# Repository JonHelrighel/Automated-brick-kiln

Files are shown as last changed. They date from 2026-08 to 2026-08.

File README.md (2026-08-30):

# Sistema Automatizado de Cozimento de Tijolos 🧱🔥

Repositório com o desenvolvimento completo do projeto de extensão do curso de **Engenharia de Controle e Automação**, cujo objetivo é projetar e construir um **forno elétrico automatizado** para a queima de tijolos cerâmicos, atendendo à demanda real da **Olaria Modesto** (Rio Grande do Sul).

O projeto é dividido em Atividades de Extensão (AE) semestrais — cada uma corresponde a uma fase do desenvolvimento do produto, seguindo a metodologia do livro *Projeto Integrado de Produtos* (BACK et al.): projeto informacional → conceitual → preliminar → detalhado → automação → retrofit.

> Este repositório é uma organização/documentação pessoal do meu projeto --> **[@JonHelrighel](https://github.com/JonHelrighel)**. O projeto é resultado de trabalho em grupo (autores abaixo) e também existe uma versão mantida por um dos colegas em [EduardoPaz01/AE-Tijolos](https://github.com/EduardoPaz01/AE-Tijolos).

## 👥 Equipe

- Eduardo Paz Putti
- João Emiliano Helrighel Freitas
- Gabriel Dettenborn
- Raian Lobato

**Curso:** Engenharia de Controle e Automação — Chapecó, SC, Brasil

## 🎯 Objetivo geral

Desenvolver e implementar um forno elétrico automatizado, capaz de atingir **até 1100 °C**, com:
- Controle automático de temperatura (malha fechada PI/PID);
- Carregamento e descarregamento automático dos tijolos (carrinho motorizado + porta guilhotina);
- Instrumentação com termopar tipo K e condicionamento de sinal;
- Supervisório (SCADA) com banco de dados e IHM para monitoramento remoto.

## 🗺️ Linha do tempo do projeto (visão geral por AE)

| Etapa | Semestre | Foco | Principais entregas |
|---|---|---|---|
| **[AE-I](./AE-I)** | 5º sem. – 2025/1 | Projeto de Produto (informacional, conceitual, preliminar) | Carta de demanda, fundamentação teórica, dimensionamentos iniciais, modelagem 3D preliminar (CAD) |
| **[AE-II](./AE-II)** | 6º sem. – 2025/2 | Mecânica e Elétrica (construção física) | Projeto mecânico detalhado, fabricação/montagem real do forno, painel elétrico, primeiros ensaios térmicos (dez/2025) |
| **[AE-III](./AE-III)** | 2026/1 | Instrumentação e Controle | Condicionamento de sinal do termopar, identificação do sistema, controladores PI/PID, firmware ESP32, ensaios de malha fechada |
| **[AE-IV](./AE-IV)** | 2026/2 (em andamento) | Automação e Redes / Supervisório | Banco de dados (MySQL), telas de IHM web (HTML), máquina de estados do supervisório |
| **AE-V** | Próximo semestre | Retrofit | Ainda não iniciado |

Cada pasta `AE-*` tem seu próprio `README.md` detalhando o que foi feito naquela etapa e explicando os arquivos/subpastas.

## 🧱 Contexto do problema

A Olaria Modesto fabrica tijolos maciços e furados em fornos a carvão com controle térmico manual e limitado, o que gera perda de peças por queima irregular, baixa agilidade no carregamento/descarregamento e alto consumo de combustível. A proposta do grupo é substituir esse processo por um **forno elétrico automatizado**, com controle preciso de temperatura e movimentação automática das peças — reduzindo perdas e padronizando a qualidade da queima.

## 🛠️ Stack / ferramentas utilizadas ao longo do projeto

- **CAD / Modelagem 3D:** SolidWorks (`.SLDPRT`, `.SLDASM`, `.SLDDRW`), exportações em `.STL` para impressão 3D
- **Simulação de circuitos:** PSIM (`.psimsch`)
- **Simulação de sistemas de controle:** MATLAB/Simulink (`.m`, `.mat`, `.slx`)
- **Diagramas (P&ID, função global, máquina de estados):** draw.io (`.drawio`)
- **Firmware:** ESP32 com ESP-IDF (C) e Arduino (`.ino`)
- **Elétrica:** EPLAN Electric P8 (`.eprj`)
- **Banco de dados:** MySQL Workbench (`.mwb`)
- **Supervisório / IHM:** HTML/JS
- **Documentação:** relatórios em `.docx`, planilhas de projeto em `.xlsx`, apresentações em `.pptx`

## 📁 Estrutura do repositório

```
.
├── AE-I/     → Projeto de produto (informacional, conceitual, preliminar)
├── AE-II/    → Projeto mecânico/elétrico detalhado + construção física
├── AE-III/   → Instrumentação, controle e firmware
├── AE-IV/    → Supervisório, banco de dados e automação de redes
├── AE-V/     → Retrofit (ainda não iniciado)
└── Referências/ → Material de apoio de disciplinas anteriores
```

## ⚠️ Nota sobre arquivos grandes

Este repositório contém arquivos de CAD (`.SLDPRT`, `.SLDASM`, `.STL`), imagens e relatórios que juntos somam algumas centenas de MB. Nenhum arquivo individual ultrapassa o limite de 100 MB do GitHub, mas para repositórios que crescerão mais (novos ensaios, mais fotos, etc.) utilizou-se **Git LFS** para os arquivos de CAD/binários.

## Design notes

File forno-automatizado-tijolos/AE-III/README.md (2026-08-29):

# AE-III — Instrumentação e Controle (2026/1)

## O que foi feito nesta etapa

Com o forno já construído fisicamente (AE-II), a AE-III foca em **instrumentar e controlar** a planta térmica: medir a temperatura de forma confiável, identificar o modelo dinâmico do forno e projetar/testar controladores automáticos (PI e PID) embarcados em um **ESP32**.

Principais atividades:

1. **Revisão do projeto informacional/conceitual** com foco em dinâmica de sistemas e controle.
2. **Instrumentação de temperatura**: termopar tipo K + placa de condicionamento de sinal (amplificação, filtro analógico passa-baixa) e conversão para leitura no ADC do ESP32.
3. **Identificação do sistema (Ensaios do forno)**: ensaios em malha aberta com diferentes níveis de potência (25%, 50%, 75%, 100%) para levantar a função de transferência do forno via MATLAB System Identification.
4. **Projeto de controladores PI e PID**, testados em malha fechada para diferentes referências de temperatura (150 °C, 300 °C, 600 °C) e perfis de rampa, com e sem filtro no sinal medido.
5. **Firmware do ESP32** (ESP-IDF, em C) implementando leitura do ADC, lógica de controle e acionamento das portas/motor.
6. **Peças mecânicas adicionais**: base/caixa e tampa do processador (impressas em 3D), sistema de fim de curso (chave/obstáculo) para detectar a posição da porta/carrinho.
7. **Projeto elétrico** completo no EPLAN (conjuntos "Controladora" e "Periféricos").
8. Relatório e apresentação da etapa, com sugestões de melhoria (filtro digital dedicado, isolação térmica melhor, alimentação trifásica para atingir a taxa de subida de 15 °C/min exigida).

## Estrutura da pasta

| Pasta/arquivo | Conteúdo |
|---|---|
| `AE3 Tijolos - Relatório.docx` / `AE3_Tijolos_VERSAO FINAL_.docx` | Relatório da etapa (versão de trabalho e versão final): introdução, objetivo geral, revisão de projeto, fundamentação teórica sobre sensores de temperatura, resultados dos ensaios de controle e sugestões de melhoria |
| `AE3 - Tijolos Apr. Inicial_.pptx` | Apresentação inicial do semestre |
| `código fim de curso.txt` | Anotações/código relacionado ao sistema de fim de curso (detecção de posição) |
| `divisor resistivo PI FORNO.psimsch` | Simulação PSIM do divisor resistivo usado no condicionamento do sinal do termopar |
| `Draw.IO (ESQUEMAS)/` | Diagramas: função global e desdobramentos da AE-III, e o **P&ID** completo do sistema (`P&ID AEIII` + PNG exportado) |
| `Projeto Elétrico/` | Projeto elétrico em EPLAN (`AE.eprj`), biblioteca de símbolos do ESP32 (`.elibz`) e PDFs dos conjuntos "Controladora" e "Periféricos" |
| `Projetos (PLANILHAS DOCS)/` | Checklist, projeto conceitual/informacional atualizados (`.xlsx`) e cronograma de prazos |
| `Impressões 3D (Arquivos STL)/` | Peça `ApoioIHM` (suporte da IHM), modelo nativo e STL para impressão |
| `Mecânica/` | Peças mecânicas da etapa: caixa/tampa/base do processador (com STL para impressão 3D e revisões), pontes H, e subpasta `Sistema do FimCurso/` (peça obstáculo + switch, usadas para detectar fim de curso da porta/carrinho) |
| `Programa de IOS ESP32/` | **Firmware do ESP32** — veja detalhamento abaixo |
| `ENSAIOS FORNO (25,50,75,100)/` | **Identificação do sistema**: ensaios em malha aberta a 25%, 50%, 75% e 100% de potência, com scripts MATLAB (`.m`), modelos identificados (`.mat`, `.slx`), gráficos e uma subpasta com o projeto de controlador PI/PID já filtrado |
| `ENSAIOS CONTROLE (TXT)/` | Dados brutos (`.txt`) dos ensaios em malha fechada: controle PI/PID para referências de 150 °C, 300 °C, 600 °C, com e sem filtro, além de rampa 50→150 °C e testes de termopar |
| `SUBIR PRO DRIVE ESSA PASTA/` | Projeto MATLAB do filtro digital do sinal do termopar (`Código Filtro Forno.m`) e workspace salvo (`.mat`), preparados para compartilhamento no Drive do grupo |

### `Programa de IOS ESP32/` — detalhamento do firmware

| Pasta | O que é |
|---|---|
| `main/` | **Código-fonte principal e mais atual** do firmware ESP-IDF: `main.c` + módulos `adc.c/h` (leitura do termopar), `controle.c/h` (lógica PI/PID), `controle_portas.c/h` (acionamento da porta/motor) e `temporizador.c/h` |
| `PROGRAMA ESP32AEIII/` | Cópia/versão paralela do mesmo firmware (mesma estrutura de `main/src`) |
| `testeESP/`, `Nova pasta/teste_forno/` | Projetos de teste do ESP-IDF — **as pastas `build/` geradas por esses projetos foram removidas** desta organização (artefatos de compilação, não código-fonte) |
| `sketch_mar27a/`, `ProgramaEsp_copy_20260320090435/` | Sketches Arduino (`.ino`) de testes pontuais/simulações |
| `Maquina de Estados Forno.drawio` | Diagrama da máquina de estados do firmware do forno |
| `DadosSimuladosEsp32.m` / `.txt`, `GraficoSimulado.jpg` | Dados e gráfico de uma simulação do comportamento do ESP32 |
| `Padronização de nomes.txt` | Convenção de nomes usada no código/projeto |
| `Untitled_0.CoolTermSettings`, `CurrentSession.CoolTermSession` | Configurações do terminal serial CoolTerm usado para monitorar a UART do ESP32 |

> ℹ️ **Nota:** os arquivos gerados por build do ESP-IDF (`build/`, `CMakeFiles/`, `esp-idf/`, bibliotecas `.a`, etc.) foram excluídos ao organizar este repositório — juntos ocupavam ~280 MB e podem ser 100% recriados a partir do código-fonte com `idf.py build`. Eles já estão listados no `.gitignore` da raiz.

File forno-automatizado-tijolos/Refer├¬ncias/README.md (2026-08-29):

# Referências

Material de apoio de disciplinas anteriores do curso, usado como base/referência para a redação dos relatórios das Atividades de Extensão (ex.: trabalho da disciplina de Introdução à Engenharia de Controle e Automação). Não faz parte do desenvolvimento técnico do forno em si.

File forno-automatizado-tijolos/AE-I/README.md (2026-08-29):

# AE-I — Projeto de Produto (5º semestre – 2025/1)

## O que foi feito nesta etapa

A AE-I é a fase inicial do projeto, focada na **concepção e documentação técnica** do forno automatizado, antes de qualquer construção física. Seguindo a metodologia de *Projeto Integrado de Produtos* (BACK et al.), o grupo percorreu:

1. **Carta de demanda** — levantamento da necessidade real da Olaria Modesto (RS): dificuldade no carregamento/descarregamento manual de tijolos e ausência de controle preciso de temperatura em fornos a carvão.
2. **Projeto informacional** — fundamentação teórica (histórico do tijolo, processo de fabricação cerâmica, estudo de caso da Cerâmica Pallotti) e definição dos requisitos do produto.
3. **Projeto conceitual** — geração e seleção de concepções para a solução (estrutura do forno, sistema de movimentação, IHM, painel elétrico).
4. **Projeto preliminar (1 e 2)** — primeiras modelagens 3D e dimensionamentos (corrente, motor, tijolos) para validar as concepções escolhidas.
5. Apresentações intermediária e final do semestre.

## Estrutura da pasta

| Pasta/arquivo | Conteúdo |
|---|---|
| `AE1 Tijolos - Carta de demanda/` | PDF com a carta de demanda de soluções tecnológicas da Olaria Modesto |
| `AE1 Tijolos - MPP.docx` | Relatório principal (Metodologia de Projeto de Produto): introdução, demanda, fundamentação teórica, projeto informacional/conceitual e referências |
| `AE1 Tijolos - Rascunho Manual.docx` | Rascunho/anotações manuscritas digitalizadas do desenvolvimento do relatório |
| `AE1 Tijolos - Projeto Informacional.xlsx` | Planilha com requisitos e especificações do produto |
| `AE1 Tijolos - Projeto Concentual.xlsx` | Planilha de geração/avaliação de concepções (matriz de decisão) |
| `AE1 Tijolos - Funcao Global e Desdobramentos.drawio` | Diagrama da função global do sistema e seus desdobramentos (entradas/saídas/subsistemas) |
| `AE1 Tijolos - Dimensionamentos/` | Cálculos de dimensionamento em SMath (`.sm`): corrente de transmissão, motor e tijolos |
| `AE1 Tijolos- Projeto Preliminar 1/` | Primeira rodada de modelagem 3D preliminar, organizada por subsistema: `CARRINHO`, `FORNO`, `IHM`, `MESA DE APOIO PRO FORNO`, `MOTOR`, `MOVIMENTAÇÃO DO CARRINHO`, `OUTRAS...` (catálogos de peças comerciais), `PAINEL ELÉTRICO`, `PORTA FORNO`, `TRILHO` |
| `AE1 Tijolos - Projeto Preliminar 2/` | Segunda rodada de projeto preliminar, refinando a modelagem anterior |
| `Montagens/` | Conjuntos montados em SolidWorks (`.SLDASM`) com desenhos técnicos (`.SLDDRW`) e PDFs exportados (ex.: `CT-00-00-XX`, `ESP_00_00_XX`) |
| `Peças/` | Peças individuais modeladas em SolidWorks (`.SLDPRT`), com desenho técnico e PDF de cada peça (nomenclatura por conjunto: `CSS`, `CT`, `ENG`, `ESP`, `ETI`, `MC`, `SPM`) |
| `AE1 Tijolos - Apr. Inicial (30-04).pptx` | Apresentação de meio de semestre |
| `AE1 Tijolos - Apr.  Festa Junina.pptx` | Apresentação em evento intermediário (Festa Junina) |
| `AE1 Tijolos - Apr. Final (16-07).pptx` | Apresentação final da AE-I |

## Convenção de nomenclatura das peças

As peças/conjuntos seguem códigos por subsistema, por exemplo:
- `CT` — Carrinho
- `ESP` — Espelho / estrutura
- `CSS`, `ENG`, `ETI`, `MC`, `SPM` — demais componentes e subconjuntos mecânicos

Cada código de peça possui até 3 arquivos irmãos: `.SLDPRT`/`.SLDASM` (modelo nativo do SolidWorks), `.SLDDRW` (desenho técnico) e `.PDF` (exportação para consulta sem precisar do SolidWorks instalado).

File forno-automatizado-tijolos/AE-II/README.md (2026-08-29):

# AE-II — Mecânica e Elétrica (6º semestre – 2025/2)

## O que foi feito nesta etapa

A AE-II é a fase de **construção física** do protótipo: o grupo saiu da modelagem 3D e partiu para a fabricação e montagem real do forno, do carrinho, da porta e do painel elétrico, além de revisar o projeto mecânico com base nas dificuldades encontradas na oficina.

Principais atividades:

1. **Revisão do projeto mecânico** (pasta `REVISAO`), incorporando ajustes descobertos durante a fabricação (ex.: adição de um novo subsistema `TAMBOR`, não previsto na AE-I).
2. **Dimensionamento das resistências elétricas** e do circuito de acionamento (simulação em PSIM).
3. **Fabricação e montagem física**, documentada dia a dia em fotos (pasta `AE2 - imagens relatório`, com uma subpasta por data de setembro a dezembro de 2025): corte e soldagem das chapas, montagem da caixa do forno, instalação da porta e isolamento térmico, montagem do painel elétrico, etc.
4. **Primeiros ensaios térmicos do protótipo montado**, em dezembro de 2025. No primeiro acionamento (17/12/2025) a temperatura atingida foi de aproximadamente 170 °C, evidenciando vazamentos térmicos que motivaram melhorias no isolamento.
5. **Descrição do P&ID** (diagrama de tubulação e instrumentação) do sistema.
6. Checklist de entregas e relatório final da etapa.

## Estrutura da pasta

| Pasta/arquivo | Conteúdo |
|---|---|
| `AE2 Tijolos - Relatório final.docx` | Relatório completo da etapa: introdução, demanda, justificativa, fundamentação teórica (termopar tipo K, transmissor HT-010, ponte H, etc.), resultados dos primeiros ensaios térmicos e conclusão |
| `AE2 - Tijlos Checklist.xlsx` | Checklist de itens/entregas da atividade |
| `AE2 - Tijolos Apr. Inicial (14-08).pptx` | Apresentação inicial do semestre |
| `P&ID descrição.xlsx` | Descrição textual do diagrama P&ID do sistema (instrumentos, malhas de controle, tubulação/fiação) |
| `AE2 - Tijolos Dimensionamentos/` | `AE2 - Esquema elétrico.psimsch` (simulação PSIM do circuito de acionamento das resistências) e `dimensionamento resistencias.sm` (cálculo de potência/dimensionamento das resistências de aquecimento) |
| `AE2 - Tijolos Projeto mecânico/` | Modelagem mecânica "como projetado" antes das correções de fabricação, organizada por subsistema: `CARRINHO`, `FORNO`, `IHM`, `MESA DE APOIO PRO FORNO`, `MOTOR`, `MOVIMENTAÇÃO DO CARRINHO`, `PAINEL ELÉTRICO`, `PORTA FORNO`, `TRILHO` |
| `REVISAO - AE2 - Tijolos Projeto mecânico/` | Versão **revisada** do projeto mecânico após ajustes de fabricação — mesmos subsistemas da pasta anterior, mais o novo subsistema `TAMBOR` |
| `AE2 - imagens relatório/` | **Diário fotográfico da montagem**, com uma pasta por data (de `set - 25 de setembro` até `dez - 18 de dezembro`), registrando cada etapa da fabricação: corte/solda das chapas, montagem da caixa e da porta, isolamento térmico, fabricação de eixos, montagem do painel elétrico e testes iniciais do forno já carregado |

## Linha do tempo da construção (pelas fotos)

- **Set/2025:** corte de chapas, soldagem da caixa do forno, isolamento das portas
- **Out/2025:** furação dos trilhos, montagem dos suportes da porta, fabricação de eixos, montagem da caixa do painel elétrico
- **Nov/2025:** porta soldada com dobradiça, corte de tijolos para teste, recepção dos tijolos de teste
- **Dez/2025:** apresentação do forno montado, forno carregado no carrinho, painel com fonte e contactora, ajustes finais e reposicionamento de suportes — **primeiros ensaios térmicos**

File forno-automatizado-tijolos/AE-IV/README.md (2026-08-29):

# AE-IV — Automação e Redes / Supervisório (2026/2 — em andamento)

## O que foi feito nesta etapa

Com o controle de temperatura já validado na AE-III, a AE-IV foca em **automação de redes e supervisório**: dar visibilidade remota ao processo por meio de um sistema SCADA simplificado, com banco de dados para histórico e uma IHM web para operação/monitoramento.

Principais atividades (em andamento):

1. **Modelagem do banco de dados** do forno (MySQL Workbench), armazenando dados de processo (temperatura, estado do ciclo, eventos).
2. **Máquina de estados do supervisório**, definindo os modos de operação do sistema (parado, aquecendo, patamar, resfriando, alarme, etc.).
3. **Desenvolvimento das telas da IHM** em HTML/JS, para visualização e controle do forno via navegador.
4. Planejamento de atividades e rubrica de avaliação da etapa.

## Estrutura da pasta

| Pasta/arquivo | Conteúdo |
|---|---|
| `Atividades de Extensão V_1 2026.docx` | Rascunho do relatório da etapa (estrutura de conclusão, sugestões de melhoria e documentos complementares) |
| ` AE4 - Tijolos Apr. Inicial_.pptx` | Apresentação inicial do semestre |
| `2026-2 - AE4 - Rubrica para Avaliação AE.xlsx` | Rubrica de avaliação da atividade, fornecida pela coordenação do curso |
| `Maquina de estados Supervisório.drawio` (+ `.png`) | Diagrama da máquina de estados do sistema supervisório |
| `Banco de Dados/` | Modelo do banco de dados do forno em MySQL Workbench: `banco_forno.mwb` (modelo atual) e `.mwb.bak` (backup) |
| `Programas-Codigos/Codigos Telas/` | Telas HTML da IHM web (ex.: `1_parametros.html`, `Tela_IHM.html`) para visualização/ajuste de parâmetros do processo |
| `supervisorio_sql_tarefas_Validar com o grupo.xlsx` | Planilha de tarefas do supervisório/SQL, para validação com o grupo |
| `Planejamento de Atividades/` | Planejamento do semestre e cópia da rubrica de avaliação |

## Status

Etapa em andamento no semestre 2026/2 — a documentação final e o relatório completo ainda serão produzidos ao longo do semestre.

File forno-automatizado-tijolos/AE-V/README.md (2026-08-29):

# AE-V — Retrofit (próximo semestre)

Esta etapa ainda **não foi iniciada**. Segundo os relatórios das etapas anteriores, a AE-V terá como foco o **retrofit** do sistema — ou seja, revisar e modernizar partes do projeto (mecânica, elétrica, controle e/ou supervisório) com base no aprendizado acumulado nas etapas AE-I a AE-IV.

Esta pasta foi criada como placeholder para manter a estrutura do repositório consistente com as demais etapas. Assim que o trabalho for iniciado, este README deve ser atualizado com:

- Objetivo específico do retrofit;
- O que foi revisado/alterado em relação às etapas anteriores;
- Resultados e conclusões.

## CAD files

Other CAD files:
forno-automatizado-tijolos/AE-I/AE1 Tijolos - Projeto Preliminar 2/Projeto Preliminar/CARRINHO/Montagens/CAR_00_00_00.SLDASM
forno-automatizado-tijolos/AE-I/AE1 Tijolos - Projeto Preliminar 2/Projeto Preliminar/FORNO/Montagens/FNR-00-03-01.SLDASM
forno-automatizado-tijolos/AE-I/AE1 Tijolos - Projeto Preliminar 2/Projeto Preliminar/MESA DE APOIO PRO FORNO/Montagem/MSA-00-00-00.SLDASM
forno-automatizado-tijolos/AE-I/AE1 Tijolos - Projeto Preliminar 2/Projeto Preliminar/MOVIMENTA├ç├âO DO CARRINHO/Montagens/ESP_00_00_02.SLDASM
forno-automatizado-tijolos/AE-I/AE1 Tijolos - Projeto Preliminar 2/Projeto Preliminar/PORTA FORNO/montagem/POR_00_03_00.SLDASM
forno-automatizado-tijolos/AE-I/AE1 Tijolos - Projeto Preliminar 2/Projeto Preliminar/TRILHO/Montagem/TRI_00_00_00.SLDASM
forno-automatizado-tijolos/AE-I/AE1 Tijolos- Projeto Preliminar 1/CARRINHO/Montagens/CAR_00_01_00.SLDASM
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

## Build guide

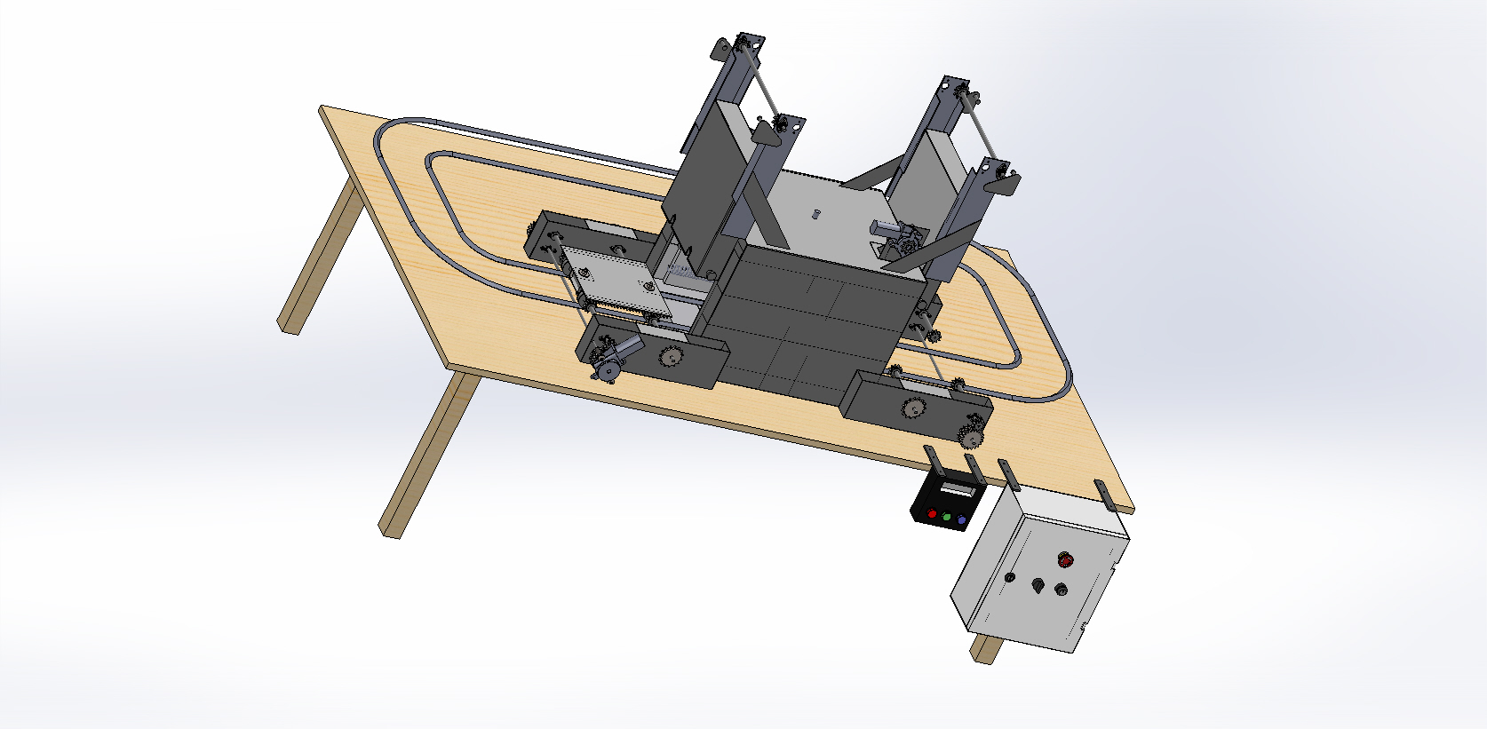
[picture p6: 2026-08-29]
forno-automatizado-tijolos/AE-I/AE1 Tijolos - Projeto Preliminar 2/Projeto Preliminar/FORNO/Montagens/FNR-00-04-01.JPG

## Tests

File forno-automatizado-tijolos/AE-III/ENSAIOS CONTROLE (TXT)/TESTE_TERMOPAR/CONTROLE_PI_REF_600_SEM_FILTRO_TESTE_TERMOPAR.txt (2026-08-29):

ets Jul 29 2019 12:21:46

rst:0x1 (POWERON_RESET),boot:0x12 (SPI_FAST_FLASH_BOOT)
configsip: 0, SPIWP:0xee
clk_drv:0x00,q_drv:0x00,d_drv:0x00,cs0_drv:0x00,hd_drv:0x00,wp_drv:0x00
mode:DIO, clock div:2
load:0x3fff0040,len:6272
load:0x40078000,len:15848
load:0x40080400,len:3920
entry 0x40080644
I (27) boot: ESP-IDF v6.0 2nd stage bootloader
I (27) boot: compile time Apr 23 2026 08:09:33
I (28) boot: Multicore bootloader
I (29) boot: chip revision: v3.1
I (31) boot.esp32: SPI Speed      : 40MHz
I (35) boot.esp32: SPI Mode       : DIO
I (39) boot.esp32: SPI Flash Size : 2MB
I (42) boot: Enabling RNG early entropy source...
I (47) boot: Partition Table:
I (49) boot: ## Label            Usage          Type ST Offset   Length
I (56) boot:  0 nvs              WiFi data        01 02 00009000 00006000
I (62) boot:  1 phy_init         RF data          01 01 0000f000 00001000
I (69) boot:  2 factory          factory app      00 00 00010000 00100000
I (75) boot: End of partition table
I (79) esp_image: segment 0: paddr=00010020 vaddr=3f400020 size=09658h ( 38488) map
I (100) esp_image: segment 1: paddr=00019680 vaddr=3ffb0000 size=02a2ch ( 10796) load
I (104) esp_image: segment 2: paddr=0001c0b4 vaddr=40080000 size=03f64h ( 16228) load
I (111) esp_image: segment 3: paddr=00020020 vaddr=400d0020 size=0f5d4h ( 62932) map
I (134) esp_image: segment 4: paddr=0002f5fc vaddr=40083f64 size=06e18h ( 28184) load
I (145) esp_image: segment 5: paddr=0003641c vaddr=50000000 size=00028h (    40) load
I (151) boot: Loaded app from partition at offset 0x10000
I (152) boot: Disabling RNG early entropy source...
I (164) cpu_start: Multicore app
I (172) cpu_start: GPIO 3 and 1 are used as console UART I/O pins
I (172) cpu_start: Pro cpu start user code
I (172) cpu_start: cpu freq: 160000000 Hz
I (174) app_init: Application information:
I (178) app_init: Project name:     app-template
I (182) app_init: App version:      1
I (186) app_init: Compile time:     Apr 23 2026 08:07:59
I (191) app_init: ELF file SHA256:  187407ae9...
I (195) app_init: ESP-IDF:          v6.0
I (199) efuse_init: Min chip rev:     v0.0
I (202) efuse_init: Max chip rev:     v3.99 
I (206) efuse_init: Chip rev:         v3.1
I (211) heap_init: Initializing. RAM available for dynamic allocation:
I (217) heap_init: At 3FFAE6E0 len 00001920 (6 KiB): DRAM
I (222) heap_init: At 3FFB3410 len 0002CBF0 (178 KiB): DRAM
I (227) heap_init: At 3FFE0440 len 00003AE0 (14 KiB): D/IRAM
I (232) heap_init: At 3FFE4350 len 0001BCB0 (111 KiB): D/IRAM
I (238) heap_init: At 4008AD7C len 00015284 (84 KiB): IRAM
I (245) spi_flash: detected chip: generic
I (247) spi_flash: flash io: dio
W (250) spi_flash: Detected size(4096k) larger than the size in the binary image header(2048k). Using the size in the binary image header.
I (263) main_task: Started on CPU0
I (273) main_task: Calling app_main()
1,1604,41.64,0.000000 
2,1604,41.64,9.235869 
3,1601,40.04,9.237197 
4,1602,40.57,9.265125 
5,1600,39.50,9.257590 
6,1595,36.82,9.276654 
7,1600,39.50,9.322321 
8,1588,33.07,9.279327 
9,1598,38.43,9.387060 
10,1600,39.50,9.299742 
11,1596,37.36,9.283344 
Forno LIGADOForno LIGADOForno LIGADOForno LIGADOForno LIGADOForno LIGADOForno LIGADOForno LIGADOForno LIGADOForno LIGADOForno LIGADOForno LIGADOForno LIGADOForno LIGADO12,1600,39.50,9.320144 
13,1600,39.50,9.286016 
14,1600,39.50,9.287349 
15,1594,36.28,9.288682 
16,1579,28.24,9.343215 
17,1603,41.11,9.477556 
18,1598,38.43,9.266115 
19,1591,34.68,9.311778 
20,1559,17.52,9.375181 
21,1602,40.57,9.660259 
22,1607,43.25,9.280377 
23,1604,41.64,9.237374 
24,1605,42.18,9.265299 
25,1602,40.57,9.257760 
26,1648,65.23,9.285686 
27,1606,42.72,8.879150 
28,1601,40.04,9.252823 
29,1612,45.93,9.298481 
30,1613,46.47,9.202280 
31,1610,44.86,9.194731 
32,1614,47.00,9.222648 
33,1611,45.40,9.188501 
34,1616,48.08,9.216416 
35,1610,44.86,9.173402 
36,1613,46.47,9.227915 
37,1617,48.61,9.202636 
38,1603,41.11,9.168485 
39,1615,47.54,9.293930 
40,1616,48.08,9.188859 
41,1621,50.76,9.181307 
42,1616,48.08,9.138286 
43,1623,51.83,9.183926 
44,1621,50.76,9.123172 
45,1626,53.44,9.142209 
46,1622,51.29,9.099182 
47,1623,51.83,9.135948 
48,1622,51.29,9.128386 
49,1630,55.58,9.138557 
50,1629,55.05,9.068929 
51,1629,55.05,9.079090 
52,1637,59.33,9.080387 
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

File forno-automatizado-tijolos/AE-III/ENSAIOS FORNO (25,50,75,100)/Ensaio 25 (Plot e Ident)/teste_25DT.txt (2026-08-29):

19,0,0.00
20,0,0.00
21,45,15.35
22,11,3.75
23,11,3.75
24,0,0.00
25,30,10.23
26,43,14.67
27,16,5.46
28,42,14.33
29,43,14.67
30,56,19.10
31,26,8.87
32,38,12.96
33,11,3.75
34,44,15.01
35,37,12.62
36,21,7.16
37,55,18.76
38,11,3.75
39,39,13.30
40,16,5.46
41,21,7.16
42,77,26.27
43,68,23.20
44,53,18.08
45,44,15.01
46,16,5.46
47,48,16.37
48,39,13.30
49,40,13.65
50,25,8.53
51,59,20.13
52,47,16.03
53,60,20.47
54,3,1.02
55,48,16.37
56,39,13.30
57,64,21.83
58,17,5.80
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

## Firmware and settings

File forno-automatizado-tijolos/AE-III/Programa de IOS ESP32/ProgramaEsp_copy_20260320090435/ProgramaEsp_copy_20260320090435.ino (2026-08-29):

// ========================================================
// PROGRAMA EM ESP-IDF (FreeRTOS) – Equivalente nativo ESP32
// (sem framework Arduino – equivalente ao "AVR bare-metal")
// Baseado na imagem do ESP32-DevKitC-K1 + Datasheet oficial
// https://documentation.espressif.com/esp32_datasheet_en.pdf
//
// Funções:
// - Leitura analógica 12 bits (GPIO34/35 – ADC1_CH6/CH7)
// - Atuação na resistência (saída digital)
// - Controle dos motores (saídas digitais)
//
// Pinos 100% compatíveis com a imagem e com o datasheet (Tabela 2 e seção 4):
// GPIO34 = ADC1_CH6 (input-only)
// GPIO35 = ADC1_CH7 (input-only)
// GPIO21, GPIO18, GPIO19, GPIO27, GPIO26 = full digital output + PWM
// ========================================================

#include <stdio.h>
#include "freertos/FreeRTOS.h"
#include "freertos/task.h"
#include "driver/gpio.h"
#include "driver/adc.h"
#include "esp_log.h"
#include "driver/dac.h"
#include "driver/ledc.h"

static const char *TAG = "ESP32_IO";

// === PINOS ===

#define R1_IN1_GPIO          (gpio_num_t)10   // ADC1_CH6  (R1-IN1)
#define R1_IN2_GPIO          (gpio_num_t)11   // ADC1_CH7  (R1-IN2)

#define DAC_2 (gpio_num_t)25
#define DAC_2 (gpio_num_t)26 

#define SPI_CLK (gpio_num_t)14
#define SPI_MISO (gpio_num_t)12
#define SPI_MOSI (gpio_num_t)13

#define SCL (gpio_num_t)22
#define SDA (gpio_num_t)21

#define MOTOR1_SAIDA1_GPIO   (gpio_num_t)19   // MOTOR1-SAIDA1
#define MOTOR1_SAIDA2_GPIO   (gpio_num_t)18   // MOTOR1-SAIDA2
#define RESISTENCIA_SAIDA_GPIO (gpio_num_t)5 // RESISTENCIA-SAIDA3

#define UART_TX (gpio_num_t)41 
#define UART_RX (gpio_num_t)40

#define MOTOR2_SAIDA1_GPIO   (gpio_num_t)2   // MOTOR2-SAIDA1
#define MOTOR2_SAIDA2_GPIO   (gpio_num_t)15   // MOTOR2-SAIDA2

void setup(){
    ESP_LOGI(TAG, "=== ESP32 ESP-IDF + FreeRTOS iniciado (baseado na imagem) ===");

    // ================== CONFIGURAÇÃO DAS SAÍDAS DIGITAIS ==================
    gpio_set_direction(MOTOR1_SAIDA1_GPIO,   GPIO_MODE_OUTPUT);
    gpio_set_direction(MOTOR1_SAIDA2_GPIO,   GPIO_MODE_OUTPUT);
    gpio_set_direction(RESISTENCIA_SAIDA_GPIO, GPIO_MODE_OUTPUT);
    gpio_set_direction(MOTOR2_SAIDA1_GPIO,   GPIO_MODE_OUTPUT);
    gpio_set_direction(MOTOR2_SAIDA2_GPIO,   GPIO_MODE_OUTPUT);
    gpio_set_direction(SPI_CLK,   GPIO_MODE_OUTPUT);
    gpio_set_direction(SPI_MISO,   GPIO_MODE_OUTPUT);
    gpio_set_direction(SPI_MOSI,   GPIO_MODE_OUTPUT);
    gpio_set_direction(UART_TX,   GPIO_MODE_OUTPUT);
    gpio_set_direction(UART_RX,   GPIO_MODE_OUTPUT);

    // Estado inicial seguro (tudo desligado)
    gpio_set_level(MOTOR1_SAIDA1_GPIO,   0);
    gpio_set_level(MOTOR1_SAIDA2_GPIO,   0);
    gpio_set_level(RESISTENCIA_SAIDA_GPIO, 0);
    gpio_set_level(MOTOR2_SAIDA1_GPIO,   0);
    gpio_set_level(MOTOR2_SAIDA2_GPIO,   0);
    gpio_set_level(SPI_CLK, 0);
    gpio_set_level(SPI_MISO, 0);
    gpio_set_level(SPI_MOSI, 0);
    gpio_set_level(UART_TX, 0);
    gpio_set_level(UART_RX, 0);

    // ================== CONFIGURAÇÃO ADC 12 BITS (datasheet seção 4.2) ==================
    adc1_config_width(ADC_WIDTH_BIT_12);                    // Resolução 12 bits (0-4095)
    adc1_config_channel_atten(ADC1_CHANNEL_6, ADC_ATTEN_DB_11); // GPIO34 – faixa ~0-3,3V
    adc1_config_channel_atten(ADC1_CHANNEL_7, ADC_ATTEN_DB_11); // GPIO35 – faixa ~0-3,3V
}


void TesteDigitais(void)
{
    gpio_set_level(MOTOR1_SAIDA1_GPIO, 1);
    gpio_set_level(MOTOR1_SAIDA2_GPIO, 1);
    gpio_set_level(MOTOR2_SAIDA1_GPIO, 1);
    gpio_set_level(MOTOR2_SAIDA2_GPIO, 1);
    gpio_set_level(SPI_CLK, 1);
    gpio_set_level(SPI_MISO, 1);
    gpio_set_level(SPI_MOSI, 1);
    gpio_set_level(UART_TX, 1);
    gpio_set_level(UART_RX, 1);
    gpio_set_level(RESISTENCIA_SAIDA_GPIO, 1);
    vTaskDelay(pdMS_TO_TICKS(100));

    gpio_set_level(MOTOR1_SAIDA1_GPIO, 0);
    gpio_set_level(MOTOR1_SAIDA2_GPIO, 0);
    gpio_set_level(MOTOR2_SAIDA1_GPIO, 0);
    gpio_set_level(MOTOR2_SAIDA2_GPIO, 0);
    gpio_set_level(SPI_CLK, 0);
    gpio_set_level(SPI_MISO, 0);
    gpio_set_level(SPI_MOSI, 0);
    gpio_set_level(UART_TX, 0);
    gpio_set_level(UART_RX, 0);
    gpio_set_level(RESISTENCIA_SAIDA_GPIO, 0);
    vTaskDelay(pdMS_TO_TICKS(100));
}

// =====================TESTE DAC (RAMPA 0 → 255 em exatamente 2 segundos) ======================
void TesteDAC(void)
{
    ESP_LOGI("TESTE_DAC", "Iniciando rampa de tensão DAC (0 → 255 em 2 segundos)...");

    // Habilita os canais DAC (GPIO25 = DAC1 e GPIO26 = DAC2 conforme datasheet e imagem)
    dac_output_enable(DAC_CHANNEL_1);
    dac_output_enable(DAC_CHANNEL_2);

    // Rampa suave: 256 passos em 2000 ms → delay de ~7,8 ms por passo
    for (int valor = 0; valor <= 255; valor++) {
        dac_output_voltage(DAC_CHANNEL_1, valor);   // DAC-1
        dac_output_voltage(DAC_CHANNEL_2, valor);   // DAC-2 (mesma rampa)
    }

    // Volta para 0V no final do teste
    dac_output_voltage(DAC_CHANNEL_1, 0);
    dac_output_voltage(DAC_CHANNEL_2, 0);

    ESP_LOGI("TESTE_DAC", "Rampa DAC concluída (tensão máxima atingida e retornada a 0V)");
}

void TestePWM(void)
{

    ESP_LOGI("TESTE_PWM", "Iniciando teste PWM rampa duty (pino %d)", MOTOR1_SAIDA1_GPIO);

    // Configuração do timer PWM
    ledc_timer_config_t timer_config = {
        .speed_mode       = LEDC_LOW_SPEED_MODE,
        .duty_resolution  = LEDC_TIMER_10_BIT,
        .timer_num        = LEDC_TIMER_0,
        .freq_hz          = 5000,
        .clk_cfg          = LEDC_AUTO_CLK
    };
    ESP_ERROR_CHECK(ledc_timer_config(&timer_config));

    // Canal PWM – ordem correta dos campos (igual ao header ledc.h)
    ledc_channel_config_t channel_config = {
        .gpio_num       = MOTOR1_SAIDA1_GPIO,
        .speed_mode     = LEDC_LOW_SPEED_MODE,
        .channel        = LEDC_CHANNEL_0,
        .intr_type      = LEDC_INTR_DISABLE,
        .timer_sel      = LEDC_TIMER_0,
        .duty           = 0,
        .hpoint         = 0
    };
    ESP_ERROR_CHECK(ledc_channel_config(&channel_config));

    // Rampa de duty 0 → 1023 em ~2 segundos
    const int passos = 1024;
    const int delay_por_passo = 2000 / passos;  // ≈ 1.95 ms por passo

    for (int duty = 0; duty <= 1023; duty++) {
        ledc_set_duty(LEDC_LOW_SPEED_MODE, LEDC_CHANNEL_0, duty);
        ledc_update_duty(LEDC_LOW_SPEED_MODE, LEDC_CHANNEL_0);
        vTaskDelay(pdMS_TO_TICKS(delay_por_passo));
    }

    // Desliga no final
    ledc_set_duty(LEDC_LOW_SPEED_MODE, LEDC_CHANNEL_0, 0);
    ledc_update_duty(LEDC_LOW_SPEED_MODE, LEDC_CHANNEL_0);

    ESP_LOGI("TESTE_PWM", "Rampa PWM finalizada");
}

void TestADC(){
    int read = analogRead(0);
}

void loop(){
    //TestePWM();
    TesteDigitais();
    TesteDAC();
}

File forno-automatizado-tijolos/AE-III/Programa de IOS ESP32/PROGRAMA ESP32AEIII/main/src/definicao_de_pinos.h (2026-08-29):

/*
 * definicao_de_pinos.h
 *
 *  Created on: 13 de abr. de 2026
 *      Author: Gabriel
 */

#ifndef MAIN_SRC_DEFINICAO_DE_PINOS_H_
#define MAIN_SRC_DEFINICAO_DE_PINOS_H_

#include "driver/gpio.h"
#include "hal/gpio_types.h"
#include "soc/gpio_num.h"

#define DEBUG 0

#define PINO_LIGA GPIO_NUM_5
#define PINO_INICIAR GPIO_NUM_22
#define PINO_MOTOR_E GPIO_NUM_19
#define PINO_MOTOR_D GPIO_NUM_18

void setup_pinos(){
	gpio_set_direction(PINO_LIGA, GPIO_MODE_INPUT);
	gpio_set_direction(PINO_INICIAR, GPIO_MODE_INPUT);
	gpio_set_direction(PINO_MOTOR_D, GPIO_MODE_OUTPUT);
	gpio_set_direction(PINO_MOTOR_E, GPIO_MODE_OUTPUT);
}

#endif /* MAIN_SRC_DEFINICAO_DE_PINOS_H_ */

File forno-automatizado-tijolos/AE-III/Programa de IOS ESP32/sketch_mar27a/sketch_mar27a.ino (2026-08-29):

// ========================================================
// PROGRAMA EM ESP-IDF (FreeRTOS) – Equivalente nativo ESP32
// (sem framework Arduino – equivalente ao "AVR bare-metal")
// Baseado na imagem do ESP32-DevKitC-K1 + Datasheet oficial
// https://documentation.espressif.com/esp32_datasheet_en.pdf
//
// Funções:
// - Leitura analógica 12 bits (GPIO34/35 – ADC1_CH6/CH7)
// - Atuação na resistência (saída digital)
// - Controle dos motores (saídas digitais)
// - Teste DAC (GPIO25 = DAC1, GPIO26 = DAC2)
// - Teste PWM via LEDC
//
// CORREÇÕES APLICADAS:
// [1] analogRead() removido — não existe no ESP-IDF; substituído por adc1_get_raw()
// [2] R1_IN1/IN2 corrigidos: GPIO10/11 → GPIO34/35 (ADC1_CH6/CH7, input-only)
// [3] DAC_2 definido duas vezes (GPIO25 e GPIO26) → corrigido para DAC_1/DAC_2
// [4] UART_RX não deve ser configurado como GPIO_MODE_OUTPUT → removido do set_direction
// [5] GPIO34/35 são input-only — NÃO chamar gpio_set_direction neles
// [6] loop()/setup() são nomes Arduino → entry point correto no ESP-IDF é app_main()
// ========================================================

#include <stdio.h>
#include "freertos/FreeRTOS.h"
#include "freertos/task.h"
#include "driver/gpio.h"
#include "driver/adc.h"
#include "driver/dac.h"
#include "driver/ledc.h"
#include "esp_log.h"

static const char *TAG = "ESP32_IO";

// ===================== PINOS =====================

// ADC — input-only, não chamar gpio_set_direction
#define ADC_CH6_GPIO    (gpio_num_t)34   // ADC1_CH6 (era GPIO10 — ERRADO)
#define ADC_CH7_GPIO    (gpio_num_t)35   // ADC1_CH7 (era GPIO11 — ERRADO)

// DAC (corrigido: eram dois #define com o mesmo nome DAC_2)
#define DAC_1_GPIO      (gpio_num_t)25   // DAC_CHANNEL_1
#define DAC_2_GPIO      (gpio_num_t)26   // DAC_CHANNEL_2

// SPI
#define SPI_CLK_GPIO    (gpio_num_t)14
#define SPI_MISO_GPIO   (gpio_num_t)12
#define SPI_MOSI_GPIO   (gpio_num_t)13

// I2C
#define SCL_GPIO        (gpio_num_t)22
#define SDA_GPIO        (gpio_num_t)21

// Motores e resistência
#define MOTOR1_SAIDA1_GPIO      (gpio_num_t)19
#define MOTOR1_SAIDA2_GPIO      (gpio_num_t)18
#define MOTOR2_SAIDA1_GPIO      (gpio_num_t)2
#define MOTOR2_SAIDA2_GPIO      (gpio_num_t)15
#define RESISTENCIA_SAIDA_GPIO  (gpio_num_t)5

// UART (TX = output, RX = input — não configurar RX como output)
#define UART_TX_GPIO    (gpio_num_t)41
#define UART_RX_GPIO    (gpio_num_t)40

// ===================== SETUP =====================

void setup(void)
{
    ESP_LOGI(TAG, "=== ESP32 ESP-IDF + FreeRTOS iniciado ===");

    // --- Saídas digitais ---
    gpio_set_direction(MOTOR1_SAIDA1_GPIO,      GPIO_MODE_OUTPUT);
    gpio_set_direction(MOTOR1_SAIDA2_GPIO,      GPIO_MODE_OUTPUT);
    gpio_set_direction(MOTOR2_SAIDA1_GPIO,      GPIO_MODE_OUTPUT);
    gpio_set_direction(MOTOR2_SAIDA2_GPIO,      GPIO_MODE_OUTPUT);
    gpio_set_direction(RESISTENCIA_SAIDA_GPIO,  GPIO_MODE_OUTPUT);
    gpio_set_direction(SPI_CLK_GPIO,            GPIO_MODE_OUTPUT);
    gpio_set_direction(SPI_MOSI_GPIO,           GPIO_MODE_OUTPUT);
    gpio_set_direction(UART_TX_GPIO,            GPIO_MODE_OUTPUT);

    // SPI_MISO e UART_RX são entradas
    gpio_set_direction(SPI_MISO_GPIO,           GPIO_MODE_INPUT);
    gpio_set_direction(UART_RX_GPIO,            GPIO_MODE_INPUT);

    // Estado inicial seguro (tudo desligado)
    gpio_set_level(MOTOR1_SAIDA1_GPIO,      0);
    gpio_set_level(MOTOR1_SAIDA2_GPIO,      0);
    gpio_set_level(MOTOR2_SAIDA1_GPIO,      0);
    gpio_set_level(MOTOR2_SAIDA2_GPIO,      0);
    gpio_set_level(RESISTENCIA_SAIDA_GPIO,  0);
    gpio_set_level(SPI_CLK_GPIO,            0);
    gpio_set_level(SPI_MOSI_GPIO,           0);
    gpio_set_level(UART_TX_GPIO,            0);

    // --- ADC 12 bits (GPIO34/35 são input-only — NÃO chamar gpio_set_direction) ---
    adc1_config_width(ADC_WIDTH_BIT_12);
    adc1_config_channel_atten(ADC1_CHANNEL_6, ADC_ATTEN_DB_11); // GPIO34 — faixa ~0–3,3V
    adc1_config_channel_atten(ADC1_CHANNEL_7, ADC_ATTEN_DB_11); // GPIO35 — faixa ~0–3,3V

    ESP_LOGI(TAG, "Setup concluído.");
}

// ===================== TESTE DIGITAIS =====================

void TesteDigitais(void)
{
    ESP_LOGI(TAG, "Teste digitais — ligando...");
    gpio_set_level(MOTOR1_SAIDA1_GPIO,      1);
    gpio_set_level(MOTOR1_SAIDA2_GPIO,      1);
    gpio_set_level(MOTOR2_SAIDA1_GPIO,      1);
    gpio_set_level(MOTOR2_SAIDA2_GPIO,      1);
    gpio_set_level(RESISTENCIA_SAIDA_GPIO,  1);
    gpio_set_level(SPI_CLK_GPIO,            1);
    gpio_set_level(SPI_MOSI_GPIO,           1);
    gpio_set_level(UART_TX_GPIO,            1);
    vTaskDelay(pdMS_TO_TICKS(100));

    ESP_LOGI(TAG, "Teste digitais — desligando...");
    gpio_set_level(MOTOR1_SAIDA1_GPIO,      0);
    gpio_set_level(MOTOR1_SAIDA2_GPIO,      0);
    gpio_set_level(MOTOR2_SAIDA1_GPIO,      0);
    gpio_set_level(MOTOR2_SAIDA2_GPIO,      0);
    gpio_set_level(RESISTENCIA_SAIDA_GPIO,  0);
    gpio_set_level(SPI_CLK_GPIO,            0);
    gpio_set_level(SPI_MOSI_GPIO,           0);
    gpio_set_level(UART_TX_GPIO,            0);
    vTaskDelay(pdMS_TO_TICKS(100));
}

// ===================== TESTE DAC =====================

void TesteDAC(void)
{
    ESP_LOGI("TESTE_DAC", "Iniciando rampa de tensão DAC (0 → 255 em 2 segundos)...");

    dac_output_enable(DAC_CHANNEL_1);   // GPIO25
    dac_output_enable(DAC_CHANNEL_2);   // GPIO26

    // 256 passos em 2000 ms → ~7,8 ms por passo
    for (int valor = 0; valor <= 255; valor++) {
        dac_output_voltage(DAC_CHANNEL_1, valor);
        dac_output_voltage(DAC_CHANNEL_2, valor);
        vTaskDelay(pdMS_TO_TICKS(8));
    }

    // Retorna a 0V
    dac_output_voltage(DAC_CHANNEL_1, 0);
    dac_output_voltage(DAC_CHANNEL_2, 0);

    ESP_LOGI("TESTE_DAC", "Rampa DAC concluída.");
}

// ===================== TESTE PWM =====================
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

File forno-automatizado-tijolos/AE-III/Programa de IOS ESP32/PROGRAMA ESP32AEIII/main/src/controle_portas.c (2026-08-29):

#include "adc.h"
#include "hal/adc_types.h"
#include <stdint.h>
#include <stdio.h>
#include <stdbool.h>
#include <sys/dirent.h>
#include <unistd.h>
#include <driver/gpio.h>

#include "controle_portas.h"
#include "definicao_de_pinos.h"



uint8_t ler_fim_de_curso(adc_oneshot_unit_handle_t * adc, uint8_t canal){
	
	int adc_read = 10;
	int med = 0;
	int reads = 6;
	uint8_t input = 0;
	
	for(int i = 0; i < reads; i++){
			adc_oneshot_read(*adc, canal, &adc_read);
			med += adc_read;
	}
			
	med = med/reads;
			
	if(med > 1900){
		input = 0b00000011;
			
	}else if (med > 1500){
		input = 0b00000010;
			
	}else if (med > 600){
		input = 0b00000001;
			
	}else{
		input = 0b00000000;
	}
	
	if(DEBUG){
	   	printf("valor ADC: %d\n", med);
		printf("input: %d\n", input);
	}
	
	return input;
}


uint8_t move_porta(uint8_t direcao, adc_oneshot_unit_handle_t * adc){
	uint8_t ret = 0;
	uint8_t input = ler_fim_de_curso(adc, CANAL_FIM_DE_CURSO);
	
		
	//liga o motor da porta
	switch (direcao) {
		case 1:
			gpio_set_level(PINO_MOTOR_D, 1);
			gpio_set_level(PINO_MOTOR_E, 0);	
		break;
		
		case 2:
			gpio_set_level(PINO_MOTOR_D, 1);
			gpio_set_level(PINO_MOTOR_E, 0);	
		break;
		
		default:
			gpio_set_level(PINO_MOTOR_D, 0);
			gpio_set_level(PINO_MOTOR_E, 0);	
		break;		
	}
		
	//desliga motor na mudaça de fim de curso
	switch (input) {
		case 1:
			if(aux_fim_curso == 2){
				ret = 1;
			}
			aux_fim_curso = 1;
		break;
			
		case 2:
			if(aux_fim_curso == 1){
				ret = 1;
			}
			aux_fim_curso = 2;
		break;
	}
	
	if(DEBUG){
		printf("direcao: %d aux_porta: %d\n",direcao, aux_fim_curso);
    	usleep(100000);
	}
	
	//desliga motores caso tenha terminado
	if(ret == 1){
		gpio_set_level(PINO_MOTOR_D, 0);
		gpio_set_level(PINO_MOTOR_E, 0);
	}
	
	return ret;
}

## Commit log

2026-08-29 Organiza e documenta AE-I a AE-IV do projeto do forno automatizado
    [2026-2 - AE4 - Rubrica para Avalia├º├úo AE.xlsx, AE1 Tijolos - Projeto Concentual.xlsx, AE1 Tijolos - Projeto Informacional.xlsx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]
2026-08-30 Revise CAD file management and Git LFS instructions
    Updated instructions regarding large files and Git LFS usage.
2026-08-30 Revise README for CAD file management and Git LFS
    Updated README to clarify Git LFS usage for CAD files and removed instructions for pushing the project to GitHub.
